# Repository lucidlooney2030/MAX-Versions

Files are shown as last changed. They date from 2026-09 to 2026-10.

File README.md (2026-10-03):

# MAX-Versions

**Current tip (2026-10-02-night):** Gen-AZ dual-rotor copper-centroid femto — see [CHAMPION.md](CHAMPION.md).

**Maximum-electricity**, **modular** generator kits — printable magnetic generators tuned for **max watts always**.

Companion to nightly `generators` exploration archives. This repo keeps the modular max-output line — shared interfaces, current champion, and drop-in kits.

## Status (2026-10-02 ET)

**Champion: Gen-AZ dual-rotor copper-centroid femto AFPM (wound-aware)** — dethrones Gen-AW (~19–40 W vs ~18–38 W @200 RPM; m2m 4.66 held; Ø20 @ R=37.5 over copper centroid; 220 t; former_web 1.20; one-plate 404×404 ≤408).

See **[CHAMPION.md](CHAMPION.md)** and **[WOUND_COIL_RULE.md](WOUND_COIL_RULE.md)**. Prior Gen-A–L were withdrawn for sizing gaps/slots to bare former STLs.

| Kit | Path |
|-----|---|
| Champion | [`champions/2026-10-02-gen-az-dual-rotor-coppercentroid-femto/`](champions/2026-10-02-gen-az-dual-rotor-coppercentroid-femto/) |
| One-plate pack | [`print-packs/gen-az-dual-rotor-coppercentroid-femto/`](print-packs/gen-az-dual-rotor-coppercentroid-femto/) |
| Night runners | [`champions/runners-2026-10-02/`](champions/runners-2026-10-02/) |
| Prior champion | [`champions/2026-10-01-gen-aw-dual-rotor-coppercentroid-pico/`](champions/2026-10-01-gen-aw-dual-rotor-coppercentroid-pico/) |

## Magnet kit (fixed)

| Magnet | Qty | Size |
|---|-----|---|
| Large disks | **16×** | Ø20 × 5 mm (N52 NdFeB) |
| Small disks | **48×** | Ø5 × 5 mm (Halbach / concentrator assist) |

Pockets are typically **Ø20.3 × 5.2** and **Ø5.3 × 5.2** for print clearance.

## Wire

- **26 AWG** — insulated OD ≈ **0.45 mm** (audit assumption)
- **30 AWG** — insulated OD ≈ **0.30 mm** (audit assumption)

Document turns, interconnect (star 3φ preferred), and **wound envelope** used for stack sizing. Gen-AZ: **220 t × 26 AWG** per pancake.

## Printer

- **Anycubic Kobra 3 Max Combo**
- Filament **1.75 mm** (PETG/ABS preferred; PLA OK for prototypes)
- Nozzles: **0.4 mm** default for carriers / formers; **0.6 / 0.8 mm** OK for endbells and coarse shells
- One-plate usable bed: **≤408×408 mm** (not full 420 — Gen-AE first plate at 440 failed)

## Modular interface

Shared mechanical stack (shaft Ø8, 608ZZ, bolt circles, etc.): **[MODULAR_INTERFACE.md](MODULAR_INTERFACE.md)**.

Kits must satisfy **[WOUND_COIL_RULE.md](WOUND_COIL_RULE.md)** before promotion to `champions/`.

## License

See [LICENSE](LICENSE).

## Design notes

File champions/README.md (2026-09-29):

# MAX-Versions champions

**Current tip (2026-09-28-night ET):** [`2026-09-28-gen-an-dual-rotor-coppercentroid-hyper/`](2026-09-28-gen-an-dual-rotor-coppercentroid-hyper/) — Gen-AN dual-rotor copper-centroid hyper (~15–32 W @200 RPM).

Prior tip: [`2026-09-27-gen-ak-dual-rotor-coppercentroid-ultra/`](2026-09-27-gen-ak-dual-rotor-coppercentroid-ultra/) — Gen-AK (~14–30 W).

Same-night runners: [`runners-2026-09-28/`](runners-2026-09-28/).

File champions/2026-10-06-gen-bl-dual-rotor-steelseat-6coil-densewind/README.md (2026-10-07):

# Gen-BL — nightly 2026-10-06 `gen-bl-dual-rotor-steelseat-6coil-densewind`

Generated 2026-10-06 (ET). All numbers from `physics_scorer` (magpylib, N52 Br 1.43 T, PLA = air, 26 AWG @20 °C,
steel back-iron by the scorer's `--back-iron` image method). Full report: [SCORE.md](SCORE.md), field plot:
[bz_midplane.png](bz_midplane.png), extra geometry checks: [GEOM_CHECK.md](GEOM_CHECK.md).

## Design idea

Dense-wind, smaller gap: the wire budget (not the window) limits these machines, so the same ~367 m of 26 AWG is laid layer-by-layer at fill 0.65 into a SHORTER 8.1 mm window (vs 9.0 mm on Gen-BI) with a 17.1 mm build on 29–71 mm sector bobbins. That shrinks the magnet-to-magnet gap 11.6 → 10.7 mm, so every turn sees more flux. Rotors, Ø5 tight-assist map and Ø134 × 4.76 mm steel are identical to Gen-BI (modular: swap in new bobbins, stator, gap sleeve and endbells).

## Honest numbers @ 200 RPM (scorer output only)

| Metric | Value |
|---|---|
| Matched-load power (3φ, V²/4R), **with steel** (`--back-iron`) | **5.299 W** (4.58 W with hot copper @60 °C) |
| Air-core what-if (same kit, no `--back-iron`) | 2.570 W (7.49 V rms/ph) |
| Without the Ø5 assists (`--back-iron --halbach none`) | 4.975 W |
| What-if: only a looser fill 0.60 wind (`--back-iron --fill 0.60`): just 522 t fit the same window (the scorer flags the 566 t claim FAIL at that fill — wind only what fits) | 4.884 W |
| Open-circuit voltage | **10.76 V rms/phase** (18.57 V line) |
| Phase resistance (20 °C) | **16.39 Ω** |
| Turns per coil | **566** (= scorer turns-fit at fill 0.65; do not raise) |
| Peak / mean-over-window Bz | 0.532 / 0.102 T |
| Matched / short-circuit current | 0.33 / 0.66 A per phase |
| Verdict | **PASS** (scorer) · geometry check **PASS** |

Topology **dual_rotor**, 8 poles, 6 coils × 1 stator, star 3φ, 2 coils in series per phase.
Copper total **367 m** of 26 AWG (6 coils × 61.2 m incl. 0.15 m leads) — inside the ~370 m budget of one ~390 m spool.
Champion to beat: Gen-BF 4.380 W (same `--back-iron` mode) → this kit **BEATS** it (1.21×).

**Honesty limits:** the `--back-iron` number is the scorer's **optimistic upper bound**: steel is modelled by first-order images of an
infinite, unsaturated plate. The magnets really sit on the steel (through-pockets), which is the image plane the scorer assumes, but
finite disc size, saturation and eddy/hysteresis losses are not modelled. Air-core coils, no AC loss, ideal series connection, 20 °C copper.

## Magnet polarity / clocking

Rotor A pocket 0 (at the D-flat / rim notch): N toward the stator; alternate N/S around. Rotor B is the same print, flipped to face A:
its pocket 0 (at its notch, which lands on the same D-flat) gets S toward the stator, alternating. Result: every magnet faces an opposite
pole directly across the gap (`rotor_b_offset_deg = 0`, `rotor_b_same_axis = true`; scorer clocking factor 1.000).
Key: D-flat bore + rim index notch = pocket 0, and the steel disc's notch lines up with it. Brace holes at [45, 135, 225, 315]° (flip-symmetric);
steel-clamp M3 holes at [0, 90, 180, 270]° (R30) and [45, 135, 225, 315]° (R63), also flip-symmetric,
so a flipped rotor only mounts aligned. Magnets: 16× Ø20×5 N52 (8 per rotor, R50) + 48× Ø5×5 N52 **diametric** assists
(24 per rotor, between poles at R40 / 50 / 60).

## ⚠️ Ø5 assist magnets — DIAMETRIC only

The 48 × Ø5×5 assists count **only if diametrically magnetised** (magnetisation across the diameter); glue them with the
magnetisation **tangential** (along the circumference), direction per the arrows on `preview.png` (scorer signs {'A': -1, 'B': 1}).
Axially magnetised Ø5 discs do **not** form a Halbach assist and are **not counted** by the scorer; if you only have axial Ø5,
leave the pockets empty and expect ≈4.97 W (scorer, same kit, `--halbach none`). Epoxy each one before the second rotor approaches —
a loose diametric magnet will spin in its pocket to align with the big magnets' field.

## Steel back-iron (REQUIRED for the scored watts)

Buy / cut **2× Ø134 × 4.76 mm (3/16") mild-steel discs** (S235/A36/1008–1018 CRS), OD Ø134, centre hole Ø26, hole map =
`print-packs/laser-cut/steel_backiron_disc.dxf` (generated from `steel_backiron_disc.scad`, same holes as the rotor). Any online
laser-cut service (SendCutSend / OSHCut / local shop) cuts it from the DXF; zinc-plate or paint against rust.
Each disc (stack) sits on the hub side of its rotor carrier around the hub; magnets drop through the pockets onto the steel and are epoxied to it.
Clamp steel + carrier with 8× M3×16 + nuts per rotor.

**Re-use note (Gen-BL):** the disc OD (Ø134), centre hole (Ø26), M3 hole map (R30 at 0/90/180/270°, R63 at 45/135/225/315°), M4 brace holes (R18 at 45°…) and rim notch are **identical to Gen-BI's** `steel_backiron_disc.dxf` (2026-10-05), and so are the rotor carriers (same pocket map) — the same steel discs and rotor carriers work for both kits (rotor STLs verified geometrically identical: same bounds and volume); print new bobbins, stator, gap sleeve and endbells.

Thickness check (`_build/steel_flux.py`, magpylib, not part of the scorer): flux entering the steel ≈ 0.278 mWb per pole.
Half of it returns each way through the disc: ≈0.54 T if it spreads over the full radial width, ≈1.46 T if it stays in a
band one magnet wide (worst case) at 4.76 mm. (At 3 mm the worst-case band would be ≈2.3 T, i.e. saturated — that is why tonight's
kits use ≥4.76 mm.) Without the steel the scorer gives only **2.57 W** — the steel is not optional.

## Parts to print (`print-packs/parts/`; all on ONE plate in `print-packs/one-plate/`)

| File | Qty | Notes |
|---|---|---|
| `rotor_face_a.stl` | 1 | flat (magnet) face down, hub up; through pockets |
| `rotor_face_b.stl` | 1 | identical pocket map (offset 0), flipped at assembly |
| `stator_core.stl` | 1 | 6 through bays, bobbins flush both faces, frame holes between stations |
| `coil_former.stl` | **6** | bobbin base, flange down |
| `coil_lid.stl` | **6** | flange down; CA-glue onto hub before winding |
| `endbell_front.stl` / `endbell_rear.stl` | 1 / 1 | 608 boss; boss side needs supports |
| `frame_standoff.stl` | 12 | 29.6 mm tubes on the M3 frame rods (stator ↔ endbells, outside the rotor) |
| `gap_sleeve.stl` | 1 | 10.7 mm shaft spacer between the two rotors (sets the gap, takes the magnet pull) |
| `gap_spacer.stl` | 6 | 0.50 mm assembly feeler shims |
| `shaft_collar.stl` | 4 | D-flat bore, M3 set screw on the flat |
| `fit_coupon.stl` | 1 | print FIRST: Ø20/Ø5 through pockets, 608 seat, D-bore, gap shim, bay slice |

One-plate: `print-packs/one-plate/one_plate_layout.stl`, bbox measured from the STL **407.9 × 408.0 mm**
(≤ 410; Kobra 3 Max 420 bed), preview `print-packs/one-plate/preview.png`. PLA/PETG, 0.4 mm nozzle, 0.20 mm layers
(0.6 mm nozzle is fine for endbells/standoffs). Binary STL, mm. Print the fit coupon on its own first (it is also on the plate).

## Hardware BOM (non-printed)

- Steel: 2× Ø134 × 4.76 mm (3/16") mild-steel discs · 2× 608 bearings · Ø8 mm D-flat shaft ≥ 134 mm (stack 99 mm + collars)
- 6× M3 threaded rod ≈ 97 mm + nuts/washers (frame) · 16× M3×16 + nuts (steel clamp)
- 2× M3 heat-set inserts (radial, in each rotor hub, below the steel) + 2× M3×6 set screws onto the D-flat; 4× M3 set screws for collars
- 4× M4 threaded rod ~150 mm + 16 nuts (TEMPORARY jack/brace rods for assembly) · 1.75 mm filament (bobbin pins) · epoxy + CA
- 367 m 26 AWG enamelled copper (0.45 mm OD)

## Winding

Bobbin window 8.10 × 17.10 mm → 18 layers, **566 turns** of 26 AWG at fill 0.65
(61.2 m per coil — use a drill/lathe winding jig and a turn counter). Copper sector r 29–71 mm × 52.68°.
Wind **before** assembly; copper only between the 0.8 mm flanges, nothing proud. Magnet→wound envelope 0.60 mm
(as-built pocket recess 0.10 mm; ≥0.5 PASS); neighbouring bobbins: clearance between neighbouring former footprints at r=29: 1.70 mm; stator web between bays ≥1.2 mm (GEOM_CHECK.md).

Wiring (3φ star, from the scorer phasors): `S0:A+ S1:C+ S2:B+ S3:A+ S4:C+ S5:B+` — same-letter coils in series per phase, '−' = swap that coil's leads.
Join the three phase ends to a common star point; take A/B/C to a 3-phase bridge rectifier (6× Schottky, e.g. SB560) for DC.
Series vs parallel: wiring the coils of each phase in parallel instead of series halves Voc and quarters R (about 5.38 V rms/ph, 4.10 Ω)
but gives the **same matched-load watts** — it only moves the load-matching point. Series is recommended (rectifier drop is a smaller fraction).

**Dense winding is required for the scored turns.** The scored turns assume a dense, layer-by-layer wind at fill 0.65 (insulated-wire area / window; the scorer cap). Use a winding jig on a drill/lathe with a turn counter, lay each layer side-by-side with light back-tension, and do not scramble-wind: a scramble wind only reaches ≈0.55–0.60 and then the window holds fewer turns (scorer what-if `--fill 0.60` is in the table above). Never wind more than the listed turns — the copper must stay below the flanges.

## Assembly order / safety

1. Print the fit coupon; check Ø20/Ø5 fit in the through-pockets, the 608 seat and the D-bore on your shaft; test-drop a wound bobbin in the bay slice.
2. Glue each lid onto its base hub, wind 566 t in 18 even layers, leads out through the lid slots.
3. Drop bobbins into the stator bays (lid/tab side = +Z, lead-groove face), pin with 1.75 mm filament, epoxy. Wire per the map above.
4. Rotor A: bolt the steel to the carrier, then seat magnets one at a time through the pockets onto the steel (polarity rule above), epoxy.
   **Keep the two magnet rotors far apart (> 30 cm) and away from steel tools** until step 6.
5. Shaft + rotor A + gap sleeve; slide the stator over the sleeve, frame rods + standoffs to the front endbell.
6. **Clap hazard — brace before seating the second magnet face:** steel-backed N52 across a 10.7 mm gap pulls very hard. Thread the 4 temporary
   M4 rods through rotor B / stator / rotor A (brace holes R18) with nuts on both sides, and lower rotor B onto the gap sleeve by turning the nuts. Never let it jump.
7. Check the gap with the 0.50 mm shims, set hub set screws + collars, fit the rear endbell.
8. **Remove the temporary M4 rods and every shim before spinning.** Spin by hand first and listen for rubbing.
9. **Brim** the 0.8 mm bobbin flanges and the thin 1.2 mm stator webs when printing.

Re-score: `/workspace/generators/tools/physics_scorer/score_kit score /workspace/generators/2026-10-06/gen-bl-dual-rotor-steelseat-6coil-densewind --out /workspace/generators/2026-10-06/gen-bl-dual-rotor-steelseat-6coil-densewind --back-iron` (air-core: drop `--back-iron`, use another `--out`).

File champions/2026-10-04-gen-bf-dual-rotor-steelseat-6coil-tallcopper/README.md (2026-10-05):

# Gen-BF — nightly 2026-10-04 `gen-bf-dual-rotor-steelseat-6coil-tallcopper`

Generated 2026-10-04 (ET). All numbers from `physics_scorer` (magpylib, N52 Br 1.43 T, PLA = air, 26 AWG @20 °C,
steel back-iron by the scorer's `--back-iron` image method). Full report: [SCORE.md](SCORE.md), field plot:
[bz_midplane.png](bz_midplane.png), extra geometry checks: [GEOM_CHECK.md](GEOM_CHECK.md).

## Design idea

8-pole / 6-coil dual rotor with big 51.5 deg sector coils and TALL 9.9 mm copper, magnets seated directly on 3 mm steel back-iron discs (through-pockets) so the field stays high across a wide gap.

## Honest numbers @ 200 RPM (scorer output only)

| Metric | Value |
|---|---|
| Matched-load power (3φ, V²/4R) | **4.380 W** (3.79 W with hot copper @60 °C) |
| Open-circuit voltage | **9.04 V rms/phase** (15.64 V line) |
| Phase resistance (20 °C) | **14.00 Ω** |
| Turns per coil | **571** (= scorer turns-fit at fill 0.60; do not raise) |
| Peak / mean-over-window Bz | 0.474 / 0.123 T |
| Matched / short-circuit current | 0.32 / 0.65 A per phase |
| Verdict | **PASS** (scorer) · geometry check **PASS** |

Topology **dual_rotor**, 8 poles, 6 coils × 1 stator, star 3φ, 2 coils in series per phase.
Copper total **314 m** of 26 AWG (6 coils × 52.3 m incl. 0.15 m leads) — fits the ~390 m spool.
Champion to beat was Gen-BE 1.684 W → this kit **BEATS** it (2.60×).

**Honesty limits:** the steel is modelled by first-order images (infinite, unsaturated plate) → upper bound. Here the magnets
really do sit on the steel (through-pockets), which is exactly the image-plane the scorer assumes (last night's kits had ~2.3 mm
of PLA between magnet and steel). Air-core, no eddy/AC loss, ideal series connection, 20 °C copper.

## Magnet polarity / clocking

Rotor A pocket 0 (at the D-flat / rim notch): N toward the stator; alternate N/S around. Rotor B is the same print, flipped to face A: its pocket 0 (at its notch, which lands on the same D-flat) gets S toward the stator, alternating. Result: every magnet faces an opposite pole directly across the gap (rotor_b_offset_deg = 0, rotor_b_same_axis = true).
Key: D-flat bore + rim index notch = pocket 0, and the steel disc's notch lines up with it. Brace holes at [45, 135, 225, 315]° (flip-symmetric);
steel-clamp M3 holes at [0, 90, 180, 270]° (R27) and [0, 90, 180, 270]° (R57), also flip-symmetric.
Magnets: 16x O20x5 N52 (8 per rotor) + 48x O5x5 N52 **diametric** assists (24 per rotor, 3 radii between poles).

## ⚠️ O5 assist magnets — DIAMETRIC only

The 48 × Ø5×5 assists **must be diametrically magnetised** (magnetisation across the diameter) and glued with the
magnetisation **tangential** (along the circumference), direction per the arrows on `preview.png` (scorer signs {'A': -1, 'B': 1}).
Axially magnetised Ø5 discs do **not** form a Halbach assist and are **not counted** by the scorer; if you only have axial Ø5,
leave the pockets empty and expect ≈4.14 W (scorer, same kit, `--halbach none`). Glue each one (CA/epoxy) before the
second rotor approaches — a loose diametric magnet will spin in its pocket to align with the big magnets' field.

## Steel back-iron (REQUIRED for the scored watts)

Buy **2× mild-steel discs Ø127 × 3 mm** (S235/A36/1008–1018 CRS), centre hole Ø26, hole map =
`print-packs/laser-cut/steel_backiron_disc.dxf` (generated from `steel_backiron_disc.scad`, same holes as the rotor). Any online
laser-cut service (SendCutSend / OSHCut / local shop) cuts this directly from the DXF; zinc-plate or paint against rust.
Each disc sits on the hub side of its rotor carrier; magnets drop through the pockets onto the steel and are epoxied to it.
Clamp disc + carrier with 8× M3×12 + nuts per rotor.
Thickness: with ~0.21 mWb per pole (magpylib, at the magnet face) the average steel flux density is ≈0.70 T at 3 mm (locally higher right
behind the magnets) — 3 mm is the minimum; 4 mm also fits the hub (10 mm) and adds margin. Do **not** use 1.5 mm (≈1.3–1.5 T average, i.e. near saturation, so the image-method watts would not hold).
Without the steel discs (air-core what-if, same kit, no `--back-iron`) the scorer gives only **2.15 W** — the steel is not optional.

## Parts to print (`print-packs/parts/`; all on ONE plate in `print-packs/one-plate/`)

| File | Qty | Notes |
|---|---|---|
| `rotor_face_a.stl` | 1 | flat (magnet) face down, hub up; through pockets |
| `rotor_face_b.stl` | 1 | identical pocket map (offset 0), flipped at assembly |
| `stator_core.stl` | 1 | 6 through bays, bobbins flush both faces, frame holes between stations |
| `coil_former.stl` | **6** | bobbin base, flange down |
| `coil_lid.stl` | **6** | flange down; CA-glue onto hub before winding |
| `endbell_front.stl` / `endbell_rear.stl` | 1 / 1 | 608 boss; boss side needs supports |
| `frame_standoff.stl` | 12 | 27.6 mm tubes on the M3 frame rods (stator ↔ endbells, outside the rotor) |
| `gap_sleeve.stl` | 1 | 12.5 mm shaft spacer between the two rotors (sets the gap, takes the magnet pull) |
| `gap_spacer.stl` | 6 | 0.50 mm assembly feeler shims |
| `shaft_collar.stl` | 4 | D-flat bore, M3 set screw on the flat |
| `fit_coupon.stl` | 1 | print FIRST: O20/O5 through pockets, 608 seat, D-bore, bay slice |

One-plate: `print-packs/one-plate/one_plate_layout.stl`, bbox measured from the STL **408.5 × 409.0 mm**
(≤ 410; Kobra 3 Max 420 bed), preview `print-packs/one-plate/preview.png`. PLA/PETG, 0.4 mm nozzle, 0.20 mm layers
(0.6 mm nozzle is fine for endbells/standoffs). Binary STL, mm.

## Hardware BOM (non-printed)

- 2× steel discs (above) · 2× 608 bearings · Ø8 mm D-flat shaft ≥ 132 mm (stack 97 mm + collars)
- 6× M3 threaded rod ≈ 95 mm + nuts/washers (frame) · 16× M3×12 + nuts (steel clamp)
- 2× M3 heat-set inserts (radial, in each rotor hub) + 2× M3×6 set screws onto the D-flat; 4× M3 set screws for collars
- 4× M4 threaded rod ~150 mm + 16 nuts (TEMPORARY jack/brace rods for assembly) · 1.75 mm filament (bobbin pins) · epoxy + CA

## Winding

Bobbin window 9.90 × 15.30 mm → 22 layers, **571 turns** of 26 AWG at fill 0.60
(52.3 m per coil — use a drill/lathe winding jig and a turn counter). Copper sector r 25–62 mm × 51.51°.
Wind **before** assembly; nothing proud of the 0.8 mm flanges. Magnet→wound envelope 0.60 mm (as-built pocket recess 0.10 mm; ≥0.5 PASS).

Wiring (3φ star, from the scorer phasors): `S0:A+ S1:C+ S2:B+ S3:A+ S4:C+ S5:B+` — same-letter coils in series per phase, '−' = swap that coil's leads.

## Assembly order / safety

1. Print the fit coupon; check Ø20/Ø5 fit in the through-pockets, the 608 seat and the D-bore on your shaft; test-drop a wound bobbin in the bay slice.
2. Glue each lid onto its base hub, wind 571 t in 22 even layers, leads out through the lid slots.
3. Drop bobbins into the stator bays (lid/tab side = +Z, lead-groove face), pin with 1.75 mm filament, epoxy. Wire per the map above.
4. Rotor A: bolt the steel disc to the carrier, then seat magnets one at a time through the pockets onto the steel (polarity rule above), epoxy.
   **Keep the two magnet rotors far apart (> 30 cm) and away from steel tools** until step 6.
5. Shaft + rotor A + gap sleeve; slide the stator over the sleeve, frame rods + standoffs to the front endbell.
6. **Clap hazard — brace before seating the second magnet face:** thread the 4 temporary M4 rods through rotor B / stator / rotor A
   (brace holes R18) with nuts on both sides, and lower rotor B onto the gap sleeve by turning the nuts. Never let it jump.
7. Check the gap with the 0.50 mm shims, set hub set screws + collars, fit the rear endbell.
8. **Remove the temporary M4 rods and every shim before spinning.** Spin by hand first and listen for rubbing.
9. **Brim** the 0.8 mm bobbin flanges and the thin stator webs (1.2 mm between bays) when printing.

## Kit magnet / wire budget

16× Ø20×5 N52 + 48× Ø5×5 N52 (diametric) + 314 m of 26 AWG (of ~390 m) + 2 steel discs.

Re-score: `/workspace/generators/tools/physics_scorer/score_kit score /workspace/generators/2026-10-04/gen-bf-dual-rotor-steelseat-6coil-tallcopper --out /workspace/generators/2026-10-04/gen-bf-dual-rotor-steelseat-6coil-tallcopper --back-iron`

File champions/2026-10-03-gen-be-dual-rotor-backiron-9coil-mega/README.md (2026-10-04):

# Gen-BE — nightly 2026-10-03 `gen-be-dual-rotor-backiron-9coil-mega`

Generated 2026-10-03. All numbers from `physics_scorer` (magpylib, N52 Br 1.43 T, PLA = air, 26 AWG @20 °C, steel back-iron images).
Full report: [SCORE.md](SCORE.md), field plot: [bz_midplane.png](bz_midplane.png).

## Design idea

Nine-coil dual-rotor with tall bobbins (former_web 3.60 mm) and two buyable mild-steel back-iron discs; image-method steel boost.

## Honest numbers @ 200 RPM

| Metric | Value |
|---|---|
| Matched-load power (3φ, V²/4R) | **1.684 W** |
| Open-circuit voltage | **2.41 V rms/phase** (4.17 V line) |
| Phase resistance (20 °C) | **2.58 Ω** |
| Turns per coil | **107** (fits; do not raise) |
| Peak / mean-over-window Bz | 0.750 / 0.436 T |
| Short-circuit current | 0.93 A/phase (resistance-limited) |
| Verdict | **PASS** |

Matched load = 2.6 Ω/phase (star); I_matched 0.47 A. Copper total 58 m (9 coils × 6.43 m).
Topology **dual_rotor**, 8 poles, 9 coils × 1 stator(s). Steel: YES (scored with --back-iron).

Baseline Gen-BA (corrected): 0.615 W. This kit BEATS that baseline.

## Magnet polarity / clocking

`rotor_b_offset_deg = 0`. Rotor A pocket 0 (at the D-flat / rim notch): N toward the stator; alternate N/S around. Rotor B is printed identically and flipped to face A: its pocket 0 (at its notch, which lands on the same D-flat) gets S toward the stator, alternating. Result: every magnet faces an opposite pole directly across the gap.
D-flat bore + rim index notch = pocket 0. Brace holes at 45/135/225/315° (flip-symmetric).

## ⚠️ Halbach assist magnets

The 48 × Ø5×5 assist magnets **must be diametrically magnetised** and installed with magnetisation tangential (along the circumference).
Axially magnetised Ø5 do **not** form a Halbach array and are not counted by the scorer. Signs from scorer: {'A': -1, 'B': 1}.

## Steel back-iron (required for scored watts)

Buy and fit **2x mild-steel discs Ø156 x 1.5 mm (buyable laser-cut / washer stock), centre hole Ø32 for hub, behind each rotor magnet face**.

Seat each disc on the **back** of the rotor (opposite the magnet face), concentric with the hub. Epoxy or screw through non-pocket areas.
Scored with `score_kit ... --back-iron` (first-order image method — optimistic upper bound assuming unsaturated infinite plates).
Without the steel discs, air-core output drops by roughly half (re-score without `--back-iron` before claiming watts).

## Parts to print (`print-packs/parts/`; one plate in `print-packs/one-plate/`)

| File | Qty | Notes |
|---|---|---|
| `rotor_face_a.stl` | 1 | print magnet face DOWN |
| `rotor_face_b.stl` | 1 | identical pocket map (offset 0) |
| `stator_core.stl` | 1 | through bays, bobbins flush both faces |
| `coil_former.stl` | **9** | bobbin base, flange down |
| `coil_lid.stl` | **9** | flange down; CA-glue onto hub before winding |
| `gap_spacer.stl` | 9 | 0.50 mm assembly shims |
| `endbell_front.stl` / `endbell_rear.stl` | 1 / 1 | both on the plate; boss side needs supports |
| `shaft_collar.stl` | 4 | D-flat bore, M3 set screw on the flat |
| `fit_coupon.stl` | 1 | print first |

One-plate: `print-packs/one-plate/one_plate_layout.stl`, measured **409.0 × 409.0 mm** (≤ 410, Kobra 3 Max 420 bed).

## Winding

Bobbin window 3.60 × 7.9 mm → 8 layers, **107 turns** of 26 AWG at fill 0.60.
Copper sector r 26–50 mm × 31.84°. Wind **before** assembly. Magnet→wound envelope 0.70 mm (≥0.5 PASS).

## Assembly order / safety

1. Print coupon; check magnet fit and D-bore on your shaft.
2. Glue each lid onto its base hub, wind 107 turns of 26 AWG in 8 even layers, leads out through lid grooves.
3. Drop bobbins into stator bays, pin with 1.75 mm filament, epoxy. Wire 3φ star per scorer map: `S0:A+ S1:A- S2:B- S3:B+ S4:B- S5:C- S6:C+ S7:C- S8:A-`.
4. Magnets per polarity rule (D-flat / notch = pocket 0). Fit steel back-iron discs on rotor backs before seating magnets if easier for your process.
5. **Brace M4 before seating the second magnet face** (clap hazard — dual faces / mid rotor attracts hard). Set gaps with 0.50 mm shims, lock collars.
6. **Brim on 0.60 mm flanges / thin webs.** Remove temporary braces and shims **before spinning**.

## Kit magnet / wire budget

16× Ø20×5 N52 + 48× Ø5×5 N52 (diametric assists) + ~58 m of 26 AWG (of ~390 m spool).

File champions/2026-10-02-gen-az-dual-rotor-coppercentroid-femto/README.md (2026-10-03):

# Gen-AZ — Dual-rotor copper-centroid femto AFPM / wound-aware 12-coil 3φ

**PRIMARY challenger vs Gen-AW** (night 2026-10-02 ET). Dual topology with `m2m=4.66 mm` + copper-centroid Ø20 @ **R=37.5** + **220 t** + `former_web=1.20` while magnet↔wound stays **0.50 mm PASS**.

**Wound gate: PASS** — see [WOUND_ENVELOPE.md](WOUND_ENVELOPE.md).

## Wound envelope (mandatory)

| Param | Value | Notes |
|---|---|---|
| Wire | **26 AWG** | insulated OD **0.45 mm**; ~1 lb spool ≈ 390 m |
| Turns | **220** / pancake | 12×220×~0.124 m ≈ **328 m** copper (fits 1 lb) |
| fill | **0.70** | packing factor |
| layers_per_face | **2** | axial layers proud of each flange |
| `wind_build_axial` | **0.63 mm** | `2 × 0.45 × 0.7` |
| `wind_build_radial` | **0.945 mm** | `3 × 0.45 × 0.7` |
| `former_web` / `flange_t` | **1.20 / 0.6 mm** | print floor LB walls |
| `former_bare_h` | **2.40 mm** | |
| `coil_envelope_h` | **3.66 mm** | bare + 2×wind_build_axial |
| `run_clear` | **0.50 mm** | magnet → **wound** (each gap) |
| `gap_spacer_h` | **1.13 mm** | `run_clear + wind_build_axial` |
| `m2m` | **4.66 mm** | `coil_envelope_h + 2×run_clear` (**NOT** bare) |
| magnet→wound | **0.50 mm** | **PASS** both sides (≥0.5) |

Stator bays expand for wound radial outline. Explicit params in `parameters.scad`. Coil window: coil_id_r=13.5, coil_od_r=61.5, span_deg=26.0 (centroid ~(13.5+61.5)/2=37.5).

## Why this design

Gen-AW: Ø20 @ R=38.0, 215 t, former_web 1.20, m2m 4.66, ~18–38 W. Gen-AZ tightens copper-centroid to **R=37.5**, adds **+5 turns** (220), keeps former_web **1.20** → envelope 3.66 / m2m **4.66**, Halbach Ø5 @ {22.5,37.5,54.5}. Midpoint ~29.5 W vs AW ~28 W.

## Magnet inventory (full kit)

| Kit | Qty | Placement |
|-----|-----|---|
| Ø20×5 | **8** | Rotor A @ R=37.5 mm, 45° steps |
| Ø20×5 | **8** | Rotor B @ R=37.5 mm, offset **+22.5°** |
| Ø5×5 | **24** | Rotor A Halbach @ R={22.5,37.5,54.5} |
| Ø5×5 | **24** | Rotor B Halbach (+22.5°) |

Pockets: **Ø20.3×5.2**, **Ø5.3×5.2**.

### Polarity map

**Rotor A (+Z):** alternate N-S (even indices N toward stator).  
**Rotor B (−Z):** alternate N-S with N toward stator on even indices (flux through coils).  
**Halbach smalls:** mid circumferential; inner/outer reinforce pole tips AND extend radial coverage onto inner/outer copper.

### ⚠️ DUAL-ROTOR CLAP WARNING
Brace with **M4 rods @ R≈68** **BEFORE** seating the second magnet face. Glue one rotor completely, dry-fit wound stator + gap_spacers, brace, then approach second rotor slowly. **Wind all 12 formers before assembly.** Ultra-micro-gap (0.50 mm) leaves **minimal** forgiveness — do not skip braces. Flanges 0.60 mm / web 1.20 mm: **print with brim**, verify no warp before winding.

## Coils

- **12** pancakes — 26 AWG × 220 t; star 3φ
- Mean turn ~0.124 m → copper budget ~328 m on 1 lb 26 AWG

## Stack

```
rotor A magnet face
  └── run_clear 0.50 mm
wound copper (+Z face)
  └── coil_envelope_h 3.66 through mid stator
wound copper (−Z face)
  └── run_clear 0.50 mm
rotor B magnet face
—— m2m = 4.66 mm ——
```

## Estimated EMF / power

Method (consistent with Gen-AW night): rough AFPM scaling from copper window area × turns × B_gap × RPM. Assumptions: N52 Halbach-boosted B_gap ≈ **0.75–1.14 T** per gap (tighter R than AW), fill 0.70, series/3φ star, dual-face coupling where topology allows.

| RPM | Est. combined RMS | Est. matched power |
|-----|---|---|
| 120 | — | ~13–19 W |
| **200** | **~23–50 V** | **~19–40 W** |
| 300 | — | ~36–60 W |
| 500–1000 | — | ~55–135 W (thermal) |

## Modular interface

| Spec | Value |
|---|---|
| Shaft | Ø8 / bore Ø8.35 |
| Bearings | 608ZZ seats Ø21.85×7.2 |
| Hub | Ø30×10 |
| Endbell / stator bolts | **6× M3 @ R=72** (Gen-E family) |
| Brace | **4× M4 @ R≈68** (REQUIRED) |
| M3 clear | Ø3.4–3.5 |
| Heat-set | M3 inserts preferred |

## Parts to print

| File | Qty | Notes |
|---|-----|---|
| `rotor_face_a.stl` | 1 | Magnet face up; brim |
| `rotor_face_b.stl` | 1 | +22.5° pocket map |
| `stator_core.stl` | 1 | Wound-sized bays |
| `coil_former.stl` | **12** | **Wind before assembly**; thin flanges + brim |
| `gap_spacer.stl` | **12** | h=`gap_spacer_h` 1.13 |
| `endbell_front.stl` | 1 | |
| `endbell_rear.stl` | 1 | (or print front ×2) |
| `shaft_collar.stl` | 4 | |
| `fit_coupon.stl` | 1 | Print first |

One-plate: see `print-packs/one-plate/` (Kobra 3 Max ≤408×408 mm). Measured bbox **404×404 mm**.

## BOM (non-print)

| Item | Qty |
|---|-----|
| NdFeB Ø20×5 N52 | 16 |
| NdFeB Ø5×5 N52 | 48 |
| 26 AWG magnet wire | ≤328 m of ~390 m spool |
| 608ZZ bearings | 2 |
| M3 heat-set inserts + bolts | as needed |
| M4 brace rods | 4 |
| Ø8 shaft | 1 |

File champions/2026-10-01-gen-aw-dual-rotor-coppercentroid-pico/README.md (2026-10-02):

# Gen-AW — Dual-rotor copper-centroid pico AFPM / wound-aware 12-coil 3φ

**PRIMARY challenger vs Gen-AT** (night 2026-10-01 ET). Dual topology with `m2m=4.66 mm` + copper-centroid Ø20 @ **R=38.0** + **215 t** + `former_web=1.20` while magnet↔wound stays **0.50 mm PASS**.

**Wound gate: PASS** — see [WOUND_ENVELOPE.md](WOUND_ENVELOPE.md).

## Wound envelope (mandatory)

| Param | Value | Notes |
|---|---|---|
| Wire | **26 AWG** | insulated OD **0.45 mm**; ~1 lb spool ≈ 390 m |
| Turns | **215** / pancake | 12×215×~0.126 m ≈ **325 m** copper (fits 1 lb) |
| fill | **0.70** | packing factor |
| layers_per_face | **2** | axial layers proud of each flange |
| `wind_build_axial` | **0.63 mm** | `2 × 0.45 × 0.7` |
| `wind_build_radial` | **0.945 mm** | `3 × 0.45 × 0.7` |
| `former_web` / `flange_t` | **1.20 / 0.6 mm** | print floor LB walls |
| `former_bare_h` | **2.40 mm** | |
| `coil_envelope_h` | **3.66 mm** | bare + 2×wind_build_axial |
| `run_clear` | **0.50 mm** | magnet → **wound** (each gap) |
| `gap_spacer_h` | **1.13 mm** | `run_clear + wind_build_axial` |
| `m2m` | **4.66 mm** | `coil_envelope_h + 2×run_clear` (**NOT** bare) |
| magnet→wound | **0.50 mm** | **PASS** both sides (≥0.5) |

Stator bays expand for wound radial outline. Explicit params in `parameters.scad`. Coil window: coil_id_r=14.0, coil_od_r=62.0, span_deg=26.0.

## Why this design

Gen-AT: Ø20 @ R=38.5, 210 t, former_web 1.22, m2m 4.68, ~17–36 W. Gen-AW tightens copper-centroid to **R=38.0**, adds **+5 turns** (215), thins former_web to **1.20** → envelope 3.66 / m2m **4.66**, Halbach Ø5 @ {23.0,38.0,55.0}. Midpoint ~28 W vs AT ~26.5 W.

## Magnet inventory (full kit)

| Kit | Qty | Placement |
|-----|-----|---|
| Ø20×5 | **8** | Rotor A @ R=38.0 mm, 45° steps |
| Ø20×5 | **8** | Rotor B @ R=38.0 mm, offset **+22.5°** |
| Ø5×5 | **24** | Rotor A Halbach @ R={23.0,38.0,55.0} |
| Ø5×5 | **24** | Rotor B Halbach (+22.5°) |

Pockets: **Ø20.3×5.2**, **Ø5.3×5.2**.

### Polarity map

**Rotor A (+Z):** alternate N-S (even indices N toward stator).  
**Rotor B (−Z):** alternate N-S with N toward stator on even indices (flux through coils).  
**Halbach smalls:** mid circumferential; inner/outer reinforce pole tips AND extend radial coverage onto inner/outer copper.

### ⚠️ DUAL-ROTOR CLAP WARNING
Brace with **M4 rods @ R≈68** **BEFORE** seating the second magnet face. Glue one rotor completely, dry-fit wound stator + gap_spacers, brace, then approach second rotor slowly. **Wind all 12 formers before assembly.** Ultra-micro-gap (0.50 mm) leaves **minimal** forgiveness — do not skip braces. Flanges 0.60 mm / web 1.20 mm: **print with brim**, verify no warp before winding.

## Coils

- **12** pancakes — 26 AWG × 215 t; star 3φ
- Mean turn ~0.126 m → copper budget ~325 m on 1 lb 26 AWG

## Stack

```
rotor A magnet face
  └── run_clear 0.50 mm
wound copper (+Z face)
  └── coil_envelope_h 3.66 through mid stator
wound copper (−Z face)
  └── run_clear 0.50 mm
rotor B magnet face
—— m2m = 4.66 mm ——
```

## Estimated EMF / power

Method (consistent with Gen-AT night): rough AFPM scaling from copper window area × turns × B_gap × RPM. Assumptions: N52 Halbach-boosted B_gap ≈ **0.74–1.12 T** per gap (tighter m2m/R than AT), fill 0.70, series/3φ star, dual-face coupling where topology allows.

| RPM | Est. combined RMS | Est. matched power |
|-----|---|---|
| 120 | — | ~12–18 W |
| **200** | **~22–48 V** | **~18–38 W** |
| 300 | — | ~34–58 W |
| 500–1000 | — | ~52–130 W (thermal) |

## Modular interface

| Spec | Value |
|---|---|
| Shaft | Ø8 / bore Ø8.35 |
| Bearings | 608ZZ seats Ø21.85×7.2 |
| Hub | Ø30×10 |
| Endbell / stator bolts | **6× M3 @ R=72** (Gen-E family) |
| Brace | **4× M4 @ R≈68** (REQUIRED) |
| M3 clear | Ø3.4–3.5 |
| Heat-set | M3 inserts preferred |

## Parts to print

| File | Qty | Notes |
|---|-----|---|
| `rotor_face_a.stl` | 1 | Magnet face up; brim |
| `rotor_face_b.stl` | 1 | +22.5° pocket map |
| `stator_core.stl` | 1 | Wound-sized bays |
| `coil_former.stl` | **12** | **Wind before assembly**; thin flanges + brim |
| `gap_spacer.stl` | **12** | h=`gap_spacer_h` 1.13 |
| `endbell_front.stl` | 1 | |
| `endbell_rear.stl` | 1 | (or print front ×2) |
| `shaft_collar.stl` | 4 | |
| `fit_coupon.stl` | 1 | Print first |

One-plate: see `print-packs/one-plate/` (Kobra 3 Max ≤408×408 mm). Measured bbox **404×404 mm**.

## BOM (non-print)

| Item | Qty |
|---|-----|
| NdFeB Ø20×5 N52 | 16 |
| NdFeB Ø5×5 N52 | 48 |
| 26 AWG magnet wire | ≤325 m of ~390 m spool |
| 608ZZ bearings | 2 |
| M3 heat-set inserts + bolts | as needed |
| M4 brace rods | 4 |
| Ø8 shaft | 1 |

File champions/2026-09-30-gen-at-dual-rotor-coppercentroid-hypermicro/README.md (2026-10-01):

# Gen-AT — Dual-rotor copper-centroid hypermicro AFPM / wound-aware 12-coil 3φ

**PRIMARY challenger vs Gen-AQ** (night 2026-09-30 ET). Dual topology with `m2m=4.68 mm` + copper-centroid Ø20 @ **R=38.5** + **210 t** + `former_web=1.22` while magnet↔wound stays **0.50 mm PASS**.

**Wound gate: PASS** — see [WOUND_ENVELOPE.md](WOUND_ENVELOPE.md).

## Wound envelope (mandatory)

| Param | Value | Notes |
|---|---|---|
| Wire | **26 AWG** | insulated OD **0.45 mm**; ~1 lb spool ≈ 390 m |
| Turns | **210** / pancake | 12×210×~0.128 m ≈ **323 m** copper (fits 1 lb) |
| fill | **0.70** | packing factor |
| layers_per_face | **2** | axial layers proud of each flange |
| `wind_build_axial` | **0.63 mm** | `2 × 0.45 × 0.7` |
| `wind_build_radial` | **0.945 mm** | `3 × 0.45 × 0.7` |
| `former_web` / `flange_t` | **1.22 / 0.6 mm** | thinner web vs prior (LB ≥1.2) |
| `former_bare_h` | **2.42 mm** | |
| `coil_envelope_h` | **3.68 mm** | bare + 2×wind_build_axial |
| `run_clear` | **0.50 mm** | magnet → **wound** (each gap) |
| `gap_spacer_h` | **1.13 mm** | `run_clear + wind_build_axial` |
| `m2m` | **4.68 mm** | `coil_envelope_h + 2×run_clear` (**NOT** bare) |
| magnet→wound | **0.50 mm** | **PASS** both sides (≥0.5) |

Stator bays expand for wound radial outline. Explicit params in `parameters.scad`. Coil window: coil_id_r=14.5, coil_od_r=62.5, span_deg=26.0.

## Why this design

Gen-AQ: Ø20 @ R=39.0, 205 t, former_web 1.25, m2m 4.71, ~16–34 W. Gen-AT tightens copper-centroid to **R=38.5**, adds **+5 turns** (210), thins former_web to **1.22** → envelope 3.68 / m2m **4.68**, Halbach Ø5 @ {23.5,38.5,55.5}. Midpoint ~26.5 W vs AQ ~25 W.

## Magnet inventory (full kit)

| Kit | Qty | Placement |
|-----|-----|---|
| Ø20×5 | **8** | Rotor A @ R=38.5 mm, 45° steps |
| Ø20×5 | **8** | Rotor B @ R=38.5 mm, offset **+22.5°** |
| Ø5×5 | **24** | Rotor A Halbach @ R={23.5,38.5,55.5} |
| Ø5×5 | **24** | Rotor B Halbach (+22.5°) |

Pockets: **Ø20.3×5.2**, **Ø5.3×5.2**.

### Polarity map

**Rotor A (+Z):** alternate N-S (even indices N toward stator).  
**Rotor B (−Z):** alternate N-S with N toward stator on even indices (flux through coils).  
**Halbach smalls:** mid circumferential; inner/outer reinforce pole tips AND extend radial coverage onto inner/outer copper.

### ⚠️ DUAL-ROTOR CLAP WARNING
Brace with **M4 rods @ R≈68** **BEFORE** seating the second magnet face. Glue one rotor completely, dry-fit wound stator + gap_spacers, brace, then approach second rotor slowly. **Wind all 12 formers before assembly.** Ultra-micro-gap (0.50 mm) leaves **minimal** forgiveness — do not skip braces. Flanges 0.60 mm / web 1.22 mm: **print with brim**, verify no warp before winding.

## Coils

- **12** pancakes — 26 AWG × 210 t; star 3φ
- Mean turn ~0.128 m → copper budget ~323 m on 1 lb 26 AWG

## Stack

```
rotor A magnet face
  └── run_clear 0.50 mm
wound copper (+Z face)
  └── coil_envelope_h 3.68 through mid stator
wound copper (−Z face)
  └── run_clear 0.50 mm
rotor B magnet face
—— m2m = 4.68 mm ——
```

## Estimated EMF / power

Method (consistent with Gen-AQ night): rough AFPM scaling from copper window area × turns × B_gap × RPM. Assumptions: N52 Halbach-boosted B_gap ≈ **0.74–1.10 T** per gap (thinner m2m + tighter overlap), fill 0.70, series/3φ star, dual-face coupling where topology allows.

| RPM | Est. combined RMS | Est. matched power |
|-----|---|---|
| 120 | — | ~11–17 W |
| **200** | **~21–46 V** | **~17–36 W** |
| 300 | — | ~32–56 W |
| 500–1000 | — | ~50–125 W (thermal) |

## Modular interface

| Spec | Value |
|---|---|
| Shaft | Ø8 / bore Ø8.35 |
| Bearings | 608ZZ seats Ø21.85×7.2 |
| Hub | Ø30×10 |
| Endbell / stator bolts | **6× M3 @ R=72** (Gen-E family) |
| Brace | **4× M4 @ R≈68** (REQUIRED) |
| M3 clear | Ø3.4–3.5 |
| Heat-set | M3 inserts preferred |

## Parts to print

| File | Qty | Notes |
|---|-----|---|
| `rotor_face_a.stl` | 1 | Magnet face up; brim |
| `rotor_face_b.stl` | 1 | +22.5° pocket map |
| `stator_core.stl` | 1 | Wound-sized bays |
| `coil_former.stl` | **12** | **Wind before assembly**; thin flanges + brim |
| `gap_spacer.stl` | **12** | h=`gap_spacer_h` 1.13 |
| `endbell_front.stl` | 1 | |
| `endbell_rear.stl` | 1 | (or print front ×2) |
| `shaft_collar.stl` | 4 | |
| `fit_coupon.stl` | 1 | Print first |

One-plate: see `print-packs/one-plate/` (Kobra 3 Max ≤408×408 mm). Measured bbox **404×404 mm**.

## BOM (non-print)

| Item | Qty |
|---|-----|
| NdFeB Ø20×5 N52 | 16 |
| NdFeB Ø5×5 N52 | 48 |
| 26 AWG magnet wire | ≤323 m of ~390 m spool |
| 608ZZ bearings | 2 |
| M3 heat-set inserts + bolts | as needed |
| M4 brace rods | 4 |
| Ø8 shaft | 1 |

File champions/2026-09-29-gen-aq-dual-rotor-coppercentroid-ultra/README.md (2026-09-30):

# Gen-AQ — Dual-rotor copper-centroid ultra AFPM / wound-aware 12-coil 3φ

**PRIMARY challenger vs Gen-AN** (night 2026-09-29 ET). Dual-rotor AFPM copper-centroid Halbach; `m2m=4.71 mm` + copper-centroid Ø20 @ **R=39.0** + **205 t** + `former_web=1.25` while magnet↔wound stays **0.50 mm PASS**.

**Wound gate: PASS** — see [WOUND_ENVELOPE.md](WOUND_ENVELOPE.md).

## Wound envelope (mandatory)

| Param | Value | Notes |
|---|---|---|
| Wire | **26 AWG** | insulated OD **0.45 mm**; ~1 lb spool ≈ 390 m |
| Turns | **205** / pancake | 12×205×~0.130 m ≈ **320 m** copper (fits 1 lb) |
| fill | **0.70** | packing factor |
| layers_per_face | **2** | axial layers proud of each flange |
| `wind_build_axial` | **0.63 mm** | `2 × 0.45 × 0.7` |
| `wind_build_radial` | **0.945 mm** | `3 × 0.45 × 0.7` |
| `former_web` / `flange_t` | **1.25 / 0.60 mm** | thinner web vs AN 1.30 (LB ≥1.2) |
| `former_bare_h` | **2.45 mm** | |
| `coil_envelope_h` | **3.71 mm** | bare + 2×wind_build_axial |
| `run_clear` | **0.50 mm** | magnet → **wound** (each gap) |
| `gap_spacer_h` | **1.13 mm** | `run_clear + wind_build_axial` |
| `m2m` | **4.71 mm** | `coil_envelope_h + 2×run_clear` (**NOT** bare) |
| magnet→wound | **0.50 mm** | **PASS** both sides (≥0.5) |

Stator bays expand for wound radial outline. Explicit params in `parameters.scad`.

## Why this design

Gen-AN: Ø20 @ R=39.5, 200 t, former_web 1.30, m2m 4.76, ~15–32 W. Gen-AQ tightens copper-centroid to **R=39.0**, adds **+5 turns** (205), thins former_web to **1.25** → envelope 3.71 / m2m **4.71**, Halbach Ø5 @ {24.0,39.0,56.0}. Midpoint ~25 W vs AN ~23.5 W.

## Magnet inventory (full kit)

| Kit | Qty | Placement |
|-----|-----|---|
| Ø20×5 | **8** | Rotor A @ R=39.0 mm, 45° steps |
| Ø20×5 | **8** | Rotor B @ R=39.0 mm, offset **+22.5°** |
| Ø5×5 | **24** | Rotor A Halbach @ R={24.0,39.0,56.0} |
| Ø5×5 | **24** | Rotor B Halbach (+22.5°) |

Pockets: **Ø20.3×5.2**, **Ø5.3×5.2**.

### Polarity map

**Rotor A (+Z):** alternate N-S (even indices N toward stator).  
**Rotor B (−Z):** alternate N-S with N toward stator on even indices (flux through coils).  
**Halbach smalls:** mid circumferential; inner/outer reinforce pole tips AND extend radial coverage onto inner/outer copper.

### ⚠️ DUAL-ROTOR CLAP WARNING
Brace with **M4 rods @ R≈68** **BEFORE** seating the second magnet face. Glue one rotor completely, dry-fit wound stator + gap_spacers, brace, then approach second rotor slowly. **Wind all 12 formers before assembly.** Ultra-micro-gap (0.50 mm) leaves **minimal** forgiveness — do not skip braces. Flanges 0.60 mm / web 1.25 mm: **print with brim**, verify no warp before winding.

## Coils

- **12** pancakes — 26 AWG × 205 t; star 3φ
- Mean turn ~0.130 m → copper budget ~320 m on 1 lb 26 AWG

## Stack

```
rotor A magnet face
  └── run_clear 0.50 mm
wound copper (+Z face)
  └── coil_envelope_h 3.71 through mid stator
wound copper (−Z face)
  └── run_clear 0.50 mm
rotor B magnet face
—— m2m = 4.71 mm ——
```

## Estimated EMF / power

Method (consistent with Gen-AN night): rough AFPM scaling from copper window area × turns × B_gap × RPM. Assumptions: N52 Halbach-boosted B_gap ≈ **0.73–1.08 T** per gap (thinner m2m + tighter overlap), fill 0.70, series/3φ star, dual-face coupling where topology allows.

| RPM | Est. combined RMS | Est. matched power |
|-----|---|---|
| 120 | ~17–22 V | ~10–16 W |
| **200** | **~20–44 V** | **~16–34 W** |
| 300 | ~30–66 V | ~30–53 W |
| 500–1000 | ~50–132 V | ~48–120 W (thermal) |

## Modular interface

| Spec | Value |
|---|---|
| Shaft | Ø8 / bore Ø8.35 |
| Bearings | 608ZZ seats Ø21.85×7.2 |
| Hub | Ø30×10 |
| Endbell / stator bolts | **6× M3 @ R=72** (Gen-E family) |
| Brace | **4× M4 @ R≈68** (REQUIRED) |
| M3 clear | Ø3.4–3.5 |
| Heat-set | M3 inserts preferred |

## Parts to print

| File | Qty | Notes |
|---|-----|---|
| `rotor_face_a.stl` | 1 | Magnet face up; brim |
| `rotor_face_b.stl` | 1 | +22.5° pocket map |
| `stator_core.stl` | 1 | Wound-sized bays |
| `coil_former.stl` | **12** | **Wind before assembly**; thin flanges + brim |
| `gap_spacer.stl` | **12** | h=`gap_spacer_h` 1.13 |
| `endbell_front.stl` | 1 | |
| `endbell_rear.stl` | 1 | (or print front ×2) |
| `shaft_collar.stl` | 4 | |
| `fit_coupon.stl` | 1 | Print first |

One-plate: see `print-packs/one-plate/` (Kobra 3 Max ≤408×408 mm). Measured bbox **404×404 mm**.

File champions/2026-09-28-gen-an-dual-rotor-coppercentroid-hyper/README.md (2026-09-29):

# Gen-AN — Dual-rotor copper-centroid hyper AFPM / wound-aware 12-coil 3φ

**PRIMARY challenger vs Gen-AK** (night 2026-09-28 ET). Dual-rotor AFPM copper-centroid Halbach; `m2m=4.76 mm` + copper-centroid Ø20 @ **R=39.5** + **200 t** + `former_web=1.3` while magnet↔wound stays **0.50 mm PASS**.

**Wound gate: PASS** — see [WOUND_ENVELOPE.md](WOUND_ENVELOPE.md).

## Wound envelope (mandatory)

| Param | Value | Notes |
|---|---|---|
| Wire | **26 AWG** | insulated OD **0.45 mm**; ~1 lb spool ≈ 390 m |
| Turns | **200** / pancake | 12×200×~0.13 m ≈ **312 m** copper (fits 1 lb) |
| fill | **0.70** | packing factor |
| layers_per_face | **2** | axial layers proud of each flange |
| `wind_build_axial` | **0.63 mm** | `2 × 0.45 × 0.7` |
| `wind_build_radial` | **0.945 mm** | `3 × 0.45 × 0.7` |
| `former_web` / `flange_t` | **1.3 / 0.60 mm** | thinner web vs prior 1.40 |
| `former_bare_h` | **2.50 mm** | |
| `coil_envelope_h` | **3.76 mm** | bare + 2×wind_build_axial |
| `run_clear` | **0.50 mm** | magnet → **wound** (each gap) |
| `gap_spacer_h` | **1.13 mm** | `run_clear + wind_build_axial` |
| `m2m` | **4.76 mm** | `coil_envelope_h + 2×run_clear` (**NOT** bare) |
| magnet→wound | **0.50 mm** | **PASS** both sides (≥0.5) |

Stator bays expand for wound radial outline. Explicit params in `parameters.scad`.

## Why this design

Gen-AK: Ø20 @ R=40, 190 t, former_web 1.40, m2m 4.86, ~14–30 W. Gen-AN tightens copper-centroid to **R=39.5**, adds **+10 turns** (200), thins former_web to **1.30** → envelope 3.76 / m2m **4.76**, Halbach Ø5 @ {24.5,39.5,56.5}. Midpoint ~23.5 W vs AK ~22 W.

## Magnet inventory (full kit)

| Kit | Qty | Placement |
|-----|-----|---|
| Ø20×5 | **8** | Rotor A @ R=39.5 mm, 45° steps |
| Ø20×5 | **8** | Rotor B @ R=39.5 mm, offset **+22.5°** |
| Ø5×5 | **24** | Rotor A Halbach @ R={24.5,39.5,56.5} |
| Ø5×5 | **24** | Rotor B Halbach (+22.5°) |

Pockets: **Ø20.3×5.2**, **Ø5.3×5.2**.

### Polarity map

**Rotor A (+Z):** alternate N-S (even indices N toward stator).  
**Rotor B (−Z):** alternate N-S with N toward stator on even indices (flux through coils).  
**Halbach smalls:** mid circumferential; inner/outer reinforce pole tips AND extend radial coverage onto inner/outer copper.

### ⚠️ DUAL-ROTOR CLAP WARNING
Brace with **M4 rods @ R≈68** **BEFORE** seating the second magnet face. Glue one rotor completely, dry-fit wound stator + gap_spacers, brace, then approach second rotor slowly. **Wind all 12 formers before assembly.** Ultra-micro-gap (0.50 mm) leaves **minimal** forgiveness — do not skip braces. Flanges 0.60 mm / web 1.30 mm: **print with brim**, verify no warp before winding.

## Coils

- **12** pancakes — 26 AWG × 200 t; star 3φ
- Mean turn ~0.13 m → copper budget ~312 m on 1 lb 26 AWG

## Stack

```
rotor A magnet face
  └── run_clear 0.50 mm
wound copper (+Z face)
  └── coil_envelope_h 3.76 through mid stator
wound copper (−Z face)
  └── run_clear 0.50 mm
rotor B magnet face
—— m2m = 4.76 mm ——
```

## Estimated EMF / power

Method (consistent with Gen-AK night): rough AFPM scaling from copper window area × turns × B_gap × RPM. Assumptions: N52 Halbach-boosted B_gap ≈ **0.72–1.05 T** per gap (thinner m2m + tighter overlap), fill 0.70, series/3φ star, dual-face coupling where topology allows.

| RPM | Est. combined RMS | Est. matched power |
|-----|---|---|
| 120 | ~16–21 V | ~9–15 W |
| **200** | **~19–42 V** | **~15–32 W** |
| 300 | ~28–63 V | ~28–50 W |
| 500–1000 | ~47–126 V | ~45–115 W (thermal) |

## Modular interface

| Spec | Value |
|---|---|
| Shaft | Ø8 / bore Ø8.35 |
| Bearings | 608ZZ seats Ø21.85×7.2 |
| Hub | Ø30×10 |
| Endbell / stator bolts | **6× M3 @ R=72** (Gen-E family) |
| Brace | **4× M4 @ R≈68** (REQUIRED) |
| M3 clear | Ø3.4–3.5 |
| Heat-set | M3 inserts preferred |

## Parts to print

| File | Qty | Notes |
|---|-----|---|
| `rotor_face_a.stl` | 1 | Magnet face up; brim |
| `rotor_face_b.stl` | 1 | +22.5° pocket map |
| `stator_core.stl` | 1 | Wound-sized bays |
| `coil_former.stl` | **12** | **Wind before assembly**; thin flanges + brim |
| `gap_spacer.stl` | **12** | h=`gap_spacer_h` 1.13 |
| `endbell_front.stl` | 1 | |
| `endbell_rear.stl` | 1 | (or print front ×2) |
| `shaft_collar.stl` | 4 | |
| `fit_coupon.stl` | 1 | Print first |

One-plate: see `print-packs/one-plate/` (Kobra 3 Max ≤408×408 mm). one-plate bbox measured after plate build.

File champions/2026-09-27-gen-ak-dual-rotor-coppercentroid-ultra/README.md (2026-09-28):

# Gen-AK — Dual-rotor copper-centroid ultra AFPM / wound-aware 12-coil 3φ

**PRIMARY challenger vs Gen-AH** (night 2026-09-27 ET). Dual magnet faces across a **ultra-micro-gap** wound mid-stator (`m2m=4.86 mm` vs Gen-AH `4.96`) + **copper-centroid** magnet placement (Ø20 @ **R=40** over copper window centroid ~40) + **190 t** + thinner `former_web=1.40` while magnet↔wound stays **0.50 mm PASS**.

**Wound gate: PASS** — see [WOUND_ENVELOPE.md](WOUND_ENVELOPE.md).

## Wound envelope (mandatory)

| Param | Value | Notes |
|---|---|---|
| Wire | **26 AWG** | insulated OD **0.45 mm**; ~1 lb spool ≈ 390 m |
| Turns | **190** / pancake | 12×190×~0.132 m ≈ **301 m** copper (fits 1 lb) |
| fill | **0.70** | packing factor |
| layers_per_face | **2** | axial layers proud of each flange |
| `wind_build_axial` | **0.63 mm** | `2 × 0.45 × 0.7` |
| `wind_build_radial` | **0.945 mm** | `3 × 0.45 × 0.7` |
| `former_web` / `flange_t` | **1.40 / 0.60 mm** | thinner web vs AH 1.50 |
| `former_bare_h` | **2.60 mm** | |
| `coil_envelope_h` | **3.86 mm** | bare + 2×wind_build_axial |
| `run_clear` | **0.50 mm** | magnet → **wound** (each gap) |
| `gap_spacer_h` | **1.13 mm** | `run_clear + wind_build_axial` |
| `m2m` | **4.86 mm** | `coil_envelope_h + 2×run_clear` (**NOT** bare) |
| magnet→wound | **0.50 mm** | **PASS** both sides (≥0.5) |

Stator bays expand for wound radial outline. Explicit params in `parameters.scad`.

## Why this beats Gen-AH

Gen-AH: Ø20 @ R=41, 180 t, former_web 1.50, m2m 4.96, ~13–28 W. Gen-AK tightens copper-centroid to **R=40**, adds **+10 turns** (190), thins former_web to **1.40** → envelope 3.86 / m2m **4.86**, Halbach Ø5 @ {25,40,57} covering the copper window. Midpoint ~22 W vs AH ~20.5 W.

## Magnet inventory (full kit)

| Kit | Qty | Placement |
|-----|-----|---|
| Ø20×5 | **8** | Rotor A @ R=40 mm, 45° steps |
| Ø20×5 | **8** | Rotor B @ R=40 mm, offset **+22.5°** |
| Ø5×5 | **24** | Rotor A Halbach @ R={25,40,57} |
| Ø5×5 | **24** | Rotor B Halbach (+22.5°) |

Pockets: **Ø20.3×5.2**, **Ø5.3×5.2**. Carrier OD **156 mm**, thick **7.5 mm**.

### Polarity map

**Rotor A (+Z):** alternate N-S (even indices N toward stator).  
**Rotor B (−Z):** alternate N-S with N toward stator on even indices (flux through coils).  
**Halbach smalls:** mid circumferential; inner/outer reinforce pole tips AND extend radial coverage onto inner/outer copper.

### ⚠️ DUAL-ROTOR CLAP WARNING
Brace with **M4 rods @ R≈68** **BEFORE** seating the second magnet face. Glue one rotor completely, dry-fit wound stator + gap_spacers, brace, then approach second rotor slowly. **Wind all 12 formers before assembly.** Ultra-micro-gap (0.50 mm) leaves **minimal** forgiveness — do not skip braces. Flanges 0.60 mm / web 1.40 mm: **print with brim**, verify no warp before winding.

## Coils

- **12** pancakes on single mid stator (3φ × 4) — dual-gap each turn
- **26 AWG × 190 t**; star 3φ
- Mean turn ~0.132 m → copper budget ~301 m on 1 lb 26 AWG

## Stack

```
rotor A magnet face
  └── run_clear 0.50 mm
wound copper (+Z face)
  └── coil_envelope_h 3.86 through mid stator
wound copper (−Z face)
  └── run_clear 0.50 mm
rotor B magnet face
—— m2m = 4.86 mm ——
```

## Estimated EMF / power

Method (consistent with Gen-AH night): rough AFPM scaling from copper window area × turns × B_gap × RPM. Assumptions: N52 Halbach-boosted B_gap ≈ **0.72–1.00 T** per gap (thinner m2m + tighter overlap), fill 0.70, series/3φ star, each coil sees **two** magnet faces.

| RPM | Est. combined RMS | Est. matched power |
|-----|---|---|
| 120 | ~11–19 V | ~8–14 W |
| **200** | **~18–40 V** | **~14–30 W** |
| 300 | ~28–60 V | ~26–48 W |
| 500–1000 | ~48–130 V | ~42–110 W (thermal) |

**vs Gen-AH (~13–28 W @200, m2m 4.96):** Gen-AK targets **~14–30 W @200** — copper-centroid @ R=40 + 190 t + m2m 4.86. Midpoint favors Gen-AK as new MAX tip pending bench.

## Modular interface

| Spec | Value |
|---|---|
| Shaft | Ø8 / bore Ø8.35 |
| Bearings | 608ZZ seats Ø21.85×7.2 |
| Hub | Ø30×10 |
| Endbell / stator bolts | **6× M3 @ R=72** (Gen-E family) |
| Brace | **4× M4 @ R≈68** (REQUIRED) |
| M3 clear | Ø3.4–3.5 |
| Heat-set | M3 inserts preferred |

## Parts to print

| File | Qty | Notes |
|---|-----|---|
| `rotor_face_a.stl` | 1 | Magnet face up; brim |
| `rotor_face_b.stl` | 1 | +22.5° pocket map |
| `stator_core.stl` | 1 | Wound-sized bays |
| `coil_former.stl` | **12** | **Wind before assembly**; thin flanges + brim |
| `gap_spacer.stl` | **12** | h=`gap_spacer_h` 1.13 |
| `endbell_front.stl` | 1 | |
| `endbell_rear.stl` | 1 | (or print front ×2) |
| `shaft_collar.stl` | 4 | |
| `fit_coupon.stl` | 1 | Print first |

One-plate: see `print-packs/one-plate/` (Kobra 3 Max ≤408×408 mm asserted; **404×404**).

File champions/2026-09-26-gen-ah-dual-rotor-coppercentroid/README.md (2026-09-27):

# Gen-AH — Dual-rotor copper-centroid hypermicro AFPM / wound-aware 12-coil 3φ

**PRIMARY challenger vs Gen-AE** (night 2026-09-26 ET). Dual magnet faces across a **hyper-micro-gap** wound mid-stator (`m2m=4.96 mm` vs Gen-AE `5.00`) + **copper-centroid** magnet placement (Ø20 @ **R=41** over copper window centroid ~41) + **180 t** restore B×N while magnet↔wound stays **0.50 mm PASS**.

**Wound gate: PASS** — see [WOUND_ENVELOPE.md](WOUND_ENVELOPE.md).

## Wound envelope (mandatory)

| Param | Value | Notes |
|---|---|---|
| Wire | **26 AWG** | insulated OD **0.45 mm**; ~1 lb spool ≈ 390 m |
| Turns | **180** / pancake | 12×180×~0.136 m ≈ **294 m** copper (fits 1 lb) |
| fill | **0.70** | packing factor |
| layers_per_face | **2** | axial layers proud of each flange |
| `wind_build_axial` | **0.63 mm** | `2 × 0.45 × 0.7` |
| `wind_build_radial` | **0.945 mm** | `3 × 0.45 × 0.7` |
| `former_web` / `flange_t` | **1.50 / 0.60 mm** | print-safe mins |
| `former_bare_h` | **2.70 mm** | |
| `coil_envelope_h` | **3.96 mm** | bare + 2×wind_build_axial |
| `run_clear` | **0.50 mm** | magnet → **wound** (each gap) |
| `gap_spacer_h` | **1.13 mm** | `run_clear + wind_build_axial` |
| `m2m` | **4.96 mm** | `coil_envelope_h + 2×run_clear` (**NOT** bare) |
| magnet→wound | **0.50 mm** | **PASS** both sides (≥0.5) |

Stator bays expand for wound radial outline. Explicit params in `parameters.scad`.

## Why this beats Gen-AE

Gen-AE magnets sit at **R=54** while copper window ID18.5–OD64 has centroid ~41. Ø20 disks at R=54 only cover ~44–64, starving **inner copper**. Gen-AH places Ø20 @ **R=41** (covers ~31–51 over centroid) + Halbach Ø5 @ {26,41,58} to extend coverage onto inner/outer copper. Also run_clear 0.50 (vs 0.52) and 180 t (vs 170).

## Magnet inventory (full kit)

| Kit | Qty | Placement |
|-----|-----|---|
| Ø20×5 | **8** | Rotor A @ R=41 mm, 45° steps |
| Ø20×5 | **8** | Rotor B @ R=41 mm, offset **+22.5°** |
| Ø5×5 | **24** | Rotor A Halbach @ R={26,41,58} |
| Ø5×5 | **24** | Rotor B Halbach (+22.5°) |

Pockets: **Ø20.3×5.2**, **Ø5.3×5.2**. Carrier OD **156 mm**, thick **7.5 mm**.

### Polarity map

**Rotor A (+Z):** alternate N-S (even indices N toward stator).  
**Rotor B (−Z):** alternate N-S with N toward stator on even indices (flux through coils).  
**Halbach smalls:** mid circumferential; inner/outer reinforce pole tips AND extend radial coverage onto inner/outer copper.

### ⚠️ DUAL-ROTOR CLAP WARNING
Brace with **M4 rods @ R≈68** **BEFORE** seating the second magnet face. Glue one rotor completely, dry-fit wound stator + gap_spacers, brace, then approach second rotor slowly. **Wind all 12 formers before assembly.** Hyper-micro-gap (0.50 mm) leaves **minimal** forgiveness — do not skip braces. Flanges 0.60 mm / web 1.50 mm: **print with brim**, verify no warp before winding.

## Coils

- **12** pancakes on single mid stator (3φ × 4) — dual-gap each turn
- **26 AWG × 180 t**; star 3φ
- Mean turn ~0.136 m → copper budget ~294 m on 1 lb 26 AWG

## Stack

```
rotor A magnet face
  └── run_clear 0.50 mm
wound copper (+Z face)
  └── coil_envelope_h 3.96 through mid stator
wound copper (−Z face)
  └── run_clear 0.50 mm
rotor B magnet face
—— m2m = 4.96 mm ——
```

## Estimated EMF / power

Method (consistent with Gen-AE night): rough AFPM scaling from copper window area × turns × B_gap × RPM. Assumptions: N52 Halbach-boosted B_gap ≈ **0.70–0.98 T** per gap (thinner m2m + better overlap), fill 0.70, series/3φ star, each coil sees **two** magnet faces.

| RPM | Est. combined RMS | Est. matched power |
|-----|---|---|
| 120 | ~10–18 V | ~7–13 W |
| **200** | **~17–38 V** | **~13–28 W** |
| 300 | ~26–56 V | ~24–45 W |
| 500–1000 | ~45–120 V | ~38–100 W (thermal) |

**vs Gen-AE (~12–26 W @200, m2m 5.00):** Gen-AH targets **~13–28 W @200** — copper-centroid magnets + 180 t + m2m 4.96. Midpoint favors Gen-AH as new MAX tip pending bench.

## Modular interface

| Spec | Value |
|---|---|
| Shaft | Ø8 / bore Ø8.35 |
| Bearings | 608ZZ seats Ø21.85×7.2 |
| Hub | Ø30×10 |
| Endbell / stator bolts | **6× M3 @ R=72** (Gen-E family) |
| Brace | **4× M4 @ R≈68** (REQUIRED) |
| M3 clear | Ø3.4–3.5 |
| Heat-set | M3 inserts preferred |

## Parts to print

| File | Qty | Notes |
|---|-----|---|
| `rotor_face_a.stl` | 1 | Magnet face up; brim |
| `rotor_face_b.stl` | 1 | +22.5° pocket map |
| `stator_core.stl` | 1 | Wound-sized bays |
| `coil_former.stl` | **12** | **Wind before assembly**; thin flanges + brim |
| `gap_spacer.stl` | **12** | h=`gap_spacer_h` 1.13 |
| `endbell_front.stl` | 1 | |
| `endbell_rear.stl` | 1 | (or print front ×2) |
| `shaft_collar.stl` | 4 | |
| `fit_coupon.stl` | 1 | Print first |

One-plate: see `print-packs/one-plate/` (Kobra 3 Max ≤408×408 mm asserted).

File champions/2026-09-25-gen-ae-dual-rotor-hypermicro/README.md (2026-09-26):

# Gen-AE — Dual-rotor HYPER-MICRO copper-max AFPM / wound-aware 12-coil 3φ

**PRIMARY challenger vs Gen-AB** (night 2026-09-25 ET). Dual magnet faces across a **hyper-micro-gap** wound mid-stator (`m2m=5.00 mm` vs Gen-AB `5.22`) + larger copper window (ID 18.5–OD 64) + **170 t** restore B×N while magnet↔wound stays **0.52 mm PASS**.

**Wound gate: PASS** — see night [WOUND_ENVELOPE.md](../WOUND_ENVELOPE.md).

## Wound envelope (mandatory)

| Param | Value | Notes |
|---|---|---|
| Wire | **26 AWG** | insulated OD **0.45 mm**; ~1 lb spool ≈ 390 m |
| Turns | **170** / pancake | 12×170×~0.130 m ≈ **265 m** copper (fits 1 lb) |
| fill | **0.70** | packing factor |
| layers_per_face | **2** | axial layers proud of each flange |
| `wind_build_axial` | **0.63 mm** | `2 × 0.45 × 0.7` |
| `wind_build_radial` | **0.945 mm** | `3 × 0.45 × 0.7` |
| `former_web` / `flange_t` | **1.50 / 0.60 mm** | thinner than Gen-AB 1.6/0.60 |
| `former_bare_h` | **2.70 mm** | |
| `coil_envelope_h` | **3.96 mm** | bare + 2×wind_build_axial |
| `run_clear` | **0.52 mm** | magnet → **wound** (each gap) |
| `gap_spacer_h` | **1.15 mm** | `run_clear + wind_build_axial` |
| `m2m` | **5.00 mm** | `coil_envelope_h + 2×run_clear` (**NOT** bare) |
| magnet→wound | **0.52 mm** | **PASS** both sides (≥0.5) |

Stator bays expand for wound radial outline. Explicit params in `parameters.scad`.

## Magnet inventory (full kit)

| Kit | Qty | Placement |
|-----|-----|---|
| Ø20×5 | **8** | Rotor A @ R=54 mm, 45° steps |
| Ø20×5 | **8** | Rotor B @ R=54 mm, offset **+22.5°** |
| Ø5×5 | **24** | Rotor A Halbach @ R={42,54,66} |
| Ø5×5 | **24** | Rotor B Halbach (+22.5°) |

Pockets: **Ø20.3×5.2**, **Ø5.3×5.2**. Carrier OD **156 mm**, thick **7.5 mm**.

### Polarity map

**Rotor A (+Z):** alternate N-S (even indices N toward stator).  
**Rotor B (−Z):** alternate N-S with N toward stator on even indices (flux through coils).  
**Halbach smalls:** mid circumferential; edge smalls reinforce pole tips.  

### ⚠️ DUAL-ROTOR CLAP WARNING
Brace with **M4 rods @ R≈68** **BEFORE** seating the second magnet face. Glue one rotor completely, dry-fit wound stator + gap_spacers, brace, then approach second rotor slowly. **Wind all 12 formers before assembly.** Hyper-micro-gap (0.52 mm) leaves **less** forgiveness than Gen-AB — do not skip braces. Flanges 0.60 mm / web 1.50 mm: print with brim, verify no warp before winding.

## Coils

- **12** pancakes on single mid stator (3φ × 4) — dual-gap each turn
- **26 AWG × 170 t**; star 3φ
- Mean turn ~0.130 m → copper budget ~265 m on 1 lb 26 AWG

## Stack

```
rotor A magnet face
  └── run_clear 0.52 mm
wound copper (+Z face)
  └── coil_envelope_h 3.96 through mid stator
wound copper (−Z face)
  └── run_clear 0.52 mm
rotor B magnet face
—— m2m = 5.00 mm ——
```

## Estimated EMF / power

Method (consistent with Gen-AB night): rough AFPM scaling from copper window area × turns × B_gap × RPM. Assumptions: N52 Halbach-boosted B_gap ≈ **0.68–0.95 T** per gap (thinner m2m vs Gen-AB), fill 0.70, series/3φ star, each coil sees **two** magnet faces.

| RPM | Est. combined RMS | Est. matched power |
|-----|---|---|
| 120 | ~9–17 V | ~6–12 W |
| **200** | **~16–35 V** | **~12–26 W** |
| 300 | ~25–52 V | ~22–42 W |
| 500–1000 | ~42–110 V | ~35–95 W (thermal) |

**vs Gen-AB (~11–23 W @200, m2m 5.22):** Gen-AE targets **~12–26 W @200** — thinner envelope (5.00 vs 5.22) + more copper (170 vs 160 t) + larger window ID18.5–OD64 (~+12% area). Midpoint argument favors Gen-AE as new MAX tip pending bench.

## Modular interface

| Spec | Value |
|---|---|
| Shaft | Ø8 / bore Ø8.35 |
| Bearings | 608ZZ seats Ø21.85×7.2 |
| Hub | Ø30×10 |
| Endbell / stator bolts | **6× M3 @ R=72** (Gen-E family) |
| Brace | **4× M4 @ R≈68** (REQUIRED) |
| M3 clear | Ø3.4–3.5 |
| Heat-set | M3 inserts preferred |

## Parts to print

| File | Qty | Notes |
|---|-----|---|
| `rotor_face_a.stl` | 1 | Magnet face up; brim |
| `rotor_face_b.stl` | 1 | +22.5° pocket map |
| `stator_core.stl` | 1 | Wound-sized bays |
| `coil_former.stl` | **12** | **Wind before assembly**; thin flanges |
| `gap_spacer.stl` | **12** | h=`gap_spacer_h` |
| `endbell_front.stl` | 1 | |
| `endbell_rear.stl` | 1 | (or ×2 of front) |
| `shaft_collar.stl` | 2–4 | |
| `fit_coupon.stl` | 1 | **Print first** |

One-plate: `print-packs/one-plate/` (Kobra 3 Max ~410×410; endbell rear = duplicate print of front STL on plate).

## BOM

- 16× Ø20×5 + 48× Ø5×5 N52
- Ø8 shaft, 2–4× 608ZZ, M3 + heat-set inserts, 4× M4 brace rod
- **26 AWG** magnet wire (~1 lb)
- Optional thin steel backing behind each rotor

## Print / safety

**0.4 mm** nozzle default. PETG/ABS preferred. Walls ≥0.8 (load 1.2). **DUAL-ROTOR CLAP.** Wind all formers first. Hyper-micro-gap + 0.60 flanges + 1.50 web demand brace rods and careful first-layer adhesion.

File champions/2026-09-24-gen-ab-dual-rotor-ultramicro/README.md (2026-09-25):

# Gen-AB — Dual-rotor ULTRA-MICRO-GAP copper-max AFPM / wound-aware 12-coil 3φ

**PRIMARY challenger vs Gen-Y** (night 2026-09-24 ET). Dual magnet faces across an **ultra-micro-gap** wound mid-stator (`m2m=5.22 mm` vs Gen-Y `5.76`) + larger copper window (ID 20–OD 62) + 160 t restore B×N while magnet↔wound stays **0.58 mm PASS**.

**Wound gate: PASS** — see night [WOUND_ENVELOPE.md](../WOUND_ENVELOPE.md).

## Wound envelope (mandatory)

| Param | Value | Notes |
|---|---|---|
| Wire | **26 AWG** | insulated OD **0.45 mm**; ~1 lb spool ≈ 390 m |
| Turns | **160** / pancake | 12×160×~0.125 m ≈ **240 m** copper (fits 1 lb) |
| fill | **0.70** | packing factor |
| layers_per_face | **2** | axial layers proud of each flange |
| `wind_build_axial` | **0.63 mm** | `2 × 0.45 × 0.7` |
| `wind_build_radial` | **0.945 mm** | `3 × 0.45 × 0.7` |
| `former_web` / `flange_t` | **1.6 / 0.60 mm** | thinner than Gen-Y 1.8/0.70 (print-safe mins) |
| `former_bare_h` | **2.8 mm** | |
| `coil_envelope_h` | **4.06 mm** | bare + 2×wind_build_axial |
| `run_clear` | **0.58 mm** | magnet → **wound** (each gap) |
| `gap_spacer_h` | **1.21 mm** | `run_clear + wind_build_axial` |
| `m2m` | **5.22 mm** | `coil_envelope_h + 2×run_clear` (**NOT** bare) |
| magnet→wound | **0.58 mm** | **PASS** both sides (≥0.5) |

Stator bays expand for wound radial outline. Explicit params in `parameters.scad`.

## Magnet inventory (full kit)

| Kit | Qty | Placement |
|-----|-----|---|
| Ø20×5 | **8** | Rotor A @ R=52 mm, 45° steps |
| Ø20×5 | **8** | Rotor B @ R=52 mm, offset **+22.5°** |
| Ø5×5 | **24** | Rotor A Halbach @ R={40,52,64} |
| Ø5×5 | **24** | Rotor B Halbach (+22.5°) |

Pockets: **Ø20.3×5.2**, **Ø5.3×5.2**. Carrier OD **152 mm**, thick **7.5 mm**.

### Polarity map

**Rotor A (+Z):** alternate N-S (even indices N toward stator).  
**Rotor B (−Z):** alternate N-S with N toward stator on even indices (flux through coils).  
**Halbach smalls:** mid circumferential; edge smalls reinforce pole tips.  

### ⚠️ DUAL-ROTOR CLAP WARNING
Brace with **M4 rods @ R≈68** **BEFORE** seating the second magnet face. Glue one rotor completely, dry-fit wound stator + gap_spacers, brace, then approach second rotor slowly. **Wind all 12 formers before assembly.** Ultra-micro-gap (0.58 mm) leaves **less** forgiveness than Gen-Y — do not skip braces. Flanges 0.60 mm: print with brim, verify no warp before winding.

## Coils

- **12** pancakes on single mid stator (3φ × 4) — dual-gap each turn
- **26 AWG × 160 t**; star 3φ
- Mean turn ~0.125 m → copper budget ~240 m on 1 lb 26 AWG

## Stack

```
rotor A magnet face
  └── run_clear 0.58 mm
wound copper (+Z face)
  └── coil_envelope_h 4.06 through mid stator
wound copper (−Z face)
  └── run_clear 0.58 mm
rotor B magnet face
—— m2m = 5.22 mm ——
```

## Estimated EMF / power

Method (consistent with Gen-Y night): rough AFPM scaling from copper window area × turns × B_gap × RPM. Assumptions: N52 Halbach-boosted B_gap ≈ **0.65–0.92 T** per gap (thinner m2m vs Gen-Y), fill 0.70, series/3φ star, each coil sees **two** magnet faces.

| RPM | Est. combined RMS | Est. matched power |
|-----|---|---|
| 120 | ~8–15 V | ~5–10 W |
| **200** | **~15–32 V** | **~11–23 W** |
| 300 | ~23–48 V | ~20–38 W |
| 500–1000 | ~38–100 V | ~30–85 W (thermal) |

**vs Gen-Y (~10–21 W @200, m2m 5.76):** Gen-AB targets **~11–23 W @200** — thinner envelope (5.22 vs 5.76) + more copper (160 vs 150 t) + larger window ID20–OD62 (~+9% area). Midpoint argument favors Gen-AB as new MAX tip pending bench.

## Modular interface

| Spec | Value |
|---|---|
| Shaft | Ø8 / bore Ø8.35 |
| Bearings | 608ZZ seats Ø21.85×7.2 |
| Hub | Ø30×10 |
| Endbell / stator bolts | **6× M3 @ R=72** (Gen-E family) |
| Brace | **4× M4 @ R≈68** (REQUIRED) |
| M3 clear | Ø3.4–3.5 |
| Heat-set | M3 inserts preferred |

## Parts to print

| File | Qty | Notes |
|---|-----|---|
| `rotor_face_a.stl` | 1 | Magnet face up; brim |
| `rotor_face_b.stl` | 1 | +22.5° pocket map |
| `stator_core.stl` | 1 | Wound-sized bays |
| `coil_former.stl` | **12** | **Wind before assembly**; thin flanges |
| `gap_spacer.stl` | **12** | h=`gap_spacer_h` |
| `endbell_front.stl` | 1 | |
| `endbell_rear.stl` | 1 | (or ×2 of front) |
| `shaft_collar.stl` | 2–4 | |
| `fit_coupon.stl` | 1 | **Print first** |

One-plate: `print-packs/one-plate/` (Kobra 3 Max ~410×410; endbell rear = duplicate print of front STL on plate).

## BOM

- 16× Ø20×5 + 48× Ø5×5 N52
- Ø8 shaft, 2–4× 608ZZ, M3 + heat-set inserts, 4× M4 brace rod
- **26 AWG** magnet wire (~1 lb)
- Optional thin steel backing behind each rotor

## Print / safety

**0.4 mm** nozzle default. PETG/ABS preferred. Walls ≥0.8 (load 1.2). **DUAL-ROTOR CLAP.** Wind all formers first. Ultra-micro-gap + 0.60 flanges demand brace rods and careful first-layer adhesion.

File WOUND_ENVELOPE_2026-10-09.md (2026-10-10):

# 2026-10-09 nightly — physics_scorer ranking (Gen-BR / BS / BT)

Scorer: `/workspace/generators/tools/physics_scorer/score_kit score <kit> --out <kit> --back-iron` (all three kits ship mild-steel back-iron discs, so the headline is the `--back-iron` number = the scorer's **optimistic image-method upper bound**; the air-core number without `--back-iron` is recorded next to it).
`score_kit sanity`: single Ø20×5 N52 surface Bz 0.3198 T (analytic 0.3198) → PASS.

Champion to beat: **Gen-BO** (`/workspace/generators/2026-10-07/gen-bo-dual-rotor-flushseat-6coil-widelip`) **5.497 W** matched-load @ 200 RPM with `--back-iron` (air-core what-if 2.713 W).

## Ranking (PASS kits by matched-load W @ 200 RPM, `--back-iron`)

| Rank | Kit | P matched (steel) | P air-core | Voc rms/ph | R Ω/ph | Turns/coil | Bz pk/mean T | Coils/poles | Wire m | Steel | Plate mm | Verdict |
|---|---|---|---|---|---|---|---|---|---|---|---|---|
| 1 | **Gen-BR** `gen-br-dual-rotor-bo-retrofit-tight-o5` | **5.507 W** | 2.727 W | 11.01 | 16.51 | 595 | 0.540/0.104 | 6c/8p | 370 | 2× Ø134 × 4.76 mm (3/16") mild-steel discs | 407.9×408.0 | PASS / geom PASS |
| 2 | **Gen-BS** `gen-bs-dual-rotor-compact-r48-wiresaver` | **5.406 W** | 2.708 W | 10.71 | 15.90 | 612 | 0.542/0.111 | 6c/8p | 356 | 2× Ø134 × 4.76 mm (3/16") mild-steel discs | 407.9×408.0 | PASS / geom PASS |
| 3 | **Gen-BT** `gen-bt-dual-rotor-9coil-r53-smooth` | **4.481 W** | 2.181 W | 9.92 | 16.47 | 521 | 0.489/0.159 | 9c/8p | 369 | 2× Ø140 × 4.76 mm (3/16") mild-steel discs | 407.9×408.0 | PASS / geom PASS |

## Design ideas

- **Gen-BR**: Rotor-only swap for Gen-BO: the diametric Ø5 assists move from ±7 mm to ±6.2 mm around the R50 pole ring (R43.8/50/56.2), the closest spacing that still leaves a 0.9 mm printed web between Ø5.3 pockets (rule ≥0.8). Everything else — bobbins, 595 t windings, stator, Ø134 steel — is Gen-BO. Tonight's 138-row refine scan (ring radius 49–51, coil radii ±0.5, build ±0.4, copper height 7.9–8.3) found nothing better: the 8p/6c flush-seat family is saturated under the ~370 m wire budget, so this is a hair-width step (about +0.2 % over Gen-BO), not a breakthrough.
- **Gen-BS**: Pull the whole machine 2 mm inward: poles at R48 (was R50) with 26–68 mm bobbins and an 18.5 mm build. Shorter mean turn length lets each coil hold 612 turns on about 356 m of copper — ~14 m less than Gen-BO, which leaves real slack on a ~390 m spool for leads, a re-wind or a short spool — for about 1.7 % less power. Same Ø134 steel discs as Gen-BO.
- **Gen-BT**: The low-cogging 8-pole / 9-coil line (winding factor 0.945) moved to a larger R53 pole ring with 36–70 mm bobbins and a 13.5 mm build, the best 9-coil row in tonight's scans (Gen-BQ was R52 / 35–70 / 12.6). Smoother to spin by hand and quieter, but still well below 6 coils under the wire budget.

## Ø5 assists on/off (scorer, `--back-iron`)

- Gen-BR: 5.507 W with diametric Ø5 vs 5.120 W without (+7.6 %)
- Gen-BS: 5.406 W with diametric Ø5 vs 4.997 W without (+8.2 %)
- Gen-BT: 4.481 W with diametric Ø5 vs 4.241 W without (+5.7 %)

## Dense-wind dependence (scorer, `--back-iron --fill 0.60` = same windows, fewer turns)

- Gen-BR: 5.507 W at fill 0.65 vs 5.088 W if only fill 0.60 is reached
- Gen-BS: 5.406 W at fill 0.65 vs 4.988 W if only fill 0.60 is reached
- Gen-BT: 4.481 W at fill 0.65 vs 4.133 W if only fill 0.60 is reached

## What the scans showed (`_design_scan/`, wire ≤ 370 m, all `--back-iron`)

- **The 8p/6c flush-seat family is saturated.** A 138-row refine around Gen-BO (pole ring R49/50/51 with the Ø5 map following it,
  bobbin inner/outer radius ±0.5 mm, radial build 17.6–18.4 mm, copper height 7.9–8.3 mm) found no row more than +0.02 % above Gen-BO.
  Every extra turn either needs more than the ~370 m wire budget or sits in weaker field.
- **Tightest legal Ø5 map:** ±6.2 mm (R43.8/50/56.2) leaves a 0.9 mm web between Ø5.3 pockets (rule ≥ 0.8) and is the only change that
  scored above Gen-BO in the scan (5.498 vs 5.488 scan-resolution) — built as Gen-BR, a rotor-only swap.
- **Taller, thinner copper loses:** 8.4–9.4 mm copper with 15.5–17 mm build: best 5.405 W (the extra gap costs more field than the turns gain).
- **Smaller ring saves copper:** poles at R48 with 26–68 mm bobbins: 5.410 W on only ≈356 m (R47: 5.38 W; R46 and 65–66.5 mm outer radius worse) —
  built as Gen-BS for wire margin on a ~390 m spool.
- **9 coils:** best R53 / 36–70 mm / 13.5 build 4.478 W (Gen-BQ 4.420 W) — built as Gen-BT for smooth torque; 9 coils still lose to 6 under the wire budget.
- **Not modellable honestly tonight (not built):** single-phase 8-coil layouts (scorer requires balanced 3φ), stator-side steel, axial Ø5 pole
  extenders, trapezoid coils. To go meaningfully past ~5.5 W the next levers are outside tonight's fixed kit: more copper (a second spool),
  higher RPM, or thicker magnets.

## Champion

**Gen-BR** at **5.507 W** (`--back-iron`, air-core 2.727 W) — BEATS Gen-BO 5.497 W (1.002×, same scoring mode).

Pushed Gen-BR to [lucidlooney2030/MAX-Versions](https://github.com/lucidlooney2030/MAX-Versions) @d0e9d2b as champion (CHAMPION.md updated; Gen-BS/BT as runners).

Archive: `/workspace/generators/2026-10-09-generators.tar.gz`

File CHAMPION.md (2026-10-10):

# Current champion — MAX-Versions

**As of 2026-10-09-night (ET): Gen-BR dual-rotor Gen-BO rotor retrofit, tightest legal Ø5 map — physics_scorer MAX tip.**

Path: [`champions/2026-10-09-gen-br-dual-rotor-bo-retrofit-tight-o5/`](champions/2026-10-09-gen-br-dual-rotor-bo-retrofit-tight-o5/)  
Print pack: [`print-packs/gen-br-dual-rotor-bo-retrofit-tight-o5/`](print-packs/gen-br-dual-rotor-bo-retrofit-tight-o5/) (one-plate STL + parts + `laser-cut/steel_backiron_disc.dxf`)

Gen-BR edges out Gen-BO on **honest** matched-load watts from `physics_scorer` (magpylib, PLA = air, N52 Br 1.43 T,
26 AWG @20 °C, steel back-iron via `--back-iron` image method = optimistic upper bound; same mode as Gen-BO):

| Metric @ 200 RPM | Gen-BR (new) | Gen-BO (prior champion) |
|---|---|---|
| Matched-load P (3φ V²/4R) | **5.507 W** | 5.497 W |
| Voc rms/phase | **11.01 V** | 11.00 V |
| R_phase @20 °C | **16.51 Ω** | 16.51 Ω |
| Turns fit / coil | **595** (fill 0.65) | 595 (fill 0.65) |
| Bz peak / mean window | **0.540 / 0.104 T** | 0.540 / 0.104 T |
| Topology | dual_rotor 8p/6c + 2× Ø134 × 4.76 mm steel | same |
| Copper | 370 m | 370 m |
| Air-core what-if (no `--back-iron`) | 2.727 W | 2.713 W |
| Verdict | **PASS** (geometry check PASS) | PASS |

That is **+0.2 %** — a hair. The 8p/6c flush-seat family is saturated under the ~370 m wire budget (a 197-row scan tonight found nothing bigger).

## What changed

Only the two rotor carriers: the diametric Ø5 assists move from ±7 mm to **±6.2 mm** around the R50 pole ring (R43.8/50/56.2), the closest
spacing that still leaves a 0.9 mm printed web between Ø5.3 pockets (rule ≥ 0.8). Bobbins, 595 t windings, stator, gap sleeve, endbells,
standoffs and the Ø134 × 4.76 mm steel discs/DXF are identical to Gen-BO — an existing Gen-BO upgrades by printing two rotors.
Ø5 assists: +7.6 % vs none (5.120 W without). Fill 0.60 what-if: 5.088 W. Clocking 0°, D-flat + notch, flip-symmetric holes, windable bobbins,
magnet→wound envelope 0.50 mm, one-plate 407.9 × 408.0 mm.

Night scorecard: [`WOUND_ENVELOPE_2026-10-09.md`](WOUND_ENVELOPE_2026-10-09.md) (= SCORECARD).

## Runners (same night, also PASS)

- Gen-BS compact R48 wire-saver — `champions/runners-2026-10-09/gen-bs-dual-rotor-compact-r48-wiresaver/` (**5.406 W**, 10.71 V rms/ph, air-core 2.708 W; only 356 m copper, 14 m spare on a ~390 m spool; same Ø134 steel)
- Gen-BT 8p/9c smooth-torque R53 — `champions/runners-2026-10-09/gen-bt-dual-rotor-9coil-r53-smooth/` (**4.481 W**, 9.92 V rms/ph, air-core 2.181 W; new Ø140 × 4.76 mm steel)

## Assembly warnings

- **Clap hazard** (steel-backed N52 across a 10.7 mm gap): use the 4 temporary M4 jack rods (R18) and lower rotor B by the nuts before seating the second magnet face.
- Remove temporary braces and gap shims before spinning; shim against the **magnet faces** (flush seat — caliper the magnets first).
- Brim on 0.8 mm flanges / 1.2 mm stator webs (and the 0.9 mm Ø5 pocket webs on the rotors).
- Ø5 assists must be **diametrically** magnetised, glued tangentially (axial Ø5 are not counted).
- Wind bobbins before assembly, dense and layer-by-layer (61.6 m per coil); do not raise turns. 370 m of a ~390 m spool — very little spare (Gen-BS leaves 14 m).

## Prior champion

Gen-BO dual-rotor flush-seat 6-coil wide-lip — `champions/2026-10-07-gen-bo-dual-rotor-flushseat-6coil-widelip/` (5.497 W). Superseded by Gen-BR 5.507 W.
Gen-BL dual-rotor steel-seat 6-coil dense-wind — `champions/2026-10-06-gen-bl-dual-rotor-steelseat-6coil-densewind/` (5.299 W). Superseded by Gen-BO 5.497 W.
Gen-BF dual-rotor steel-seat 6-coil tall-copper — `champions/2026-10-04-gen-bf-dual-rotor-steelseat-6coil-tallcopper/` (4.380 W). Superseded by Gen-BL 5.299 W.
Gen-BE dual-rotor backiron 9-coil mega — `champions/2026-10-03-gen-be-dual-rotor-backiron-9coil-mega/` (1.684 W). Superseded by Gen-BF 4.380 W.
Corrected Gen-BA mid-rotor (0.615 W) remains the air-core mid baseline in the generators workspace `2026-10-02-fixed/`.

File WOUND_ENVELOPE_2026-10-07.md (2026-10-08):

# 2026-10-07 nightly — physics_scorer ranking (Gen-BO / BP / BQ)

Scorer: `/workspace/generators/tools/physics_scorer/score_kit score <kit> --out <kit> --back-iron` (all three kits ship mild-steel back-iron discs, so the headline is the `--back-iron` number = the scorer's **optimistic image-method upper bound**; the air-core number without `--back-iron` is recorded next to it).
`score_kit sanity`: single Ø20×5 N52 surface Bz 0.3198 T (analytic 0.3198) → PASS.

Champion to beat: **Gen-BL** (`/workspace/generators/2026-10-06/gen-bl-dual-rotor-steelseat-6coil-densewind`) **5.299 W** matched-load @ 200 RPM with `--back-iron` (air-core what-if 2.570 W).

## Ranking (PASS kits by matched-load W @ 200 RPM, `--back-iron`)

| Rank | Kit | P matched (steel) | P air-core | Voc rms/ph | R Ω/ph | Turns/coil | Bz pk/mean T | Coils/poles | Wire m | Steel | Plate mm | Verdict |
|---|---|---|---|---|---|---|---|---|---|---|---|---|
| 1 | **Gen-BO** `gen-bo-dual-rotor-flushseat-6coil-widelip` | **5.497 W** | 2.713 W | 11.00 | 16.51 | 595 | 0.540/0.104 | 6c/8p | 370 | 2× Ø134 × 4.76 mm (3/16") mild-steel discs | 407.9×408.0 | PASS / geom PASS |
| 2 | **Gen-BP** `gen-bp-dual-rotor-flushseat-bl-retrofit` | **5.460 W** | 2.688 W | 10.92 | 16.39 | 566 | 0.540/0.104 | 6c/8p | 367 | 2× Ø134 × 4.76 mm (3/16") mild-steel discs | 407.9×408.0 | PASS / geom PASS |
| 3 | **Gen-BQ** `gen-bq-dual-rotor-flushseat-9coil-widelip` | **4.420 W** | 2.150 W | 9.80 | 16.30 | 486 | 0.489/0.156 | 9c/8p | 365 | 2× Ø138 × 4.76 mm (3/16") mild-steel discs | 407.9×408.0 | PASS / geom PASS |

## Design ideas

- **Gen-BO**: Flush seat + wider copper + tight assists: the magnets sit on the steel in 5.00 mm through-pockets (carrier = magnet height, recess 0 instead of 0.10 mm), so the magnet faces are 0.2 mm closer while still exactly 0.50 mm from the wound envelope; the bobbin lip beyond the copper is trimmed 1.0 → 0.8 mm (still the 0.8 mm wall minimum, stator web still 1.2 mm), which widens each copper sector by ~0.6° on 28–70 mm × 18.0 mm-build bobbins; and the diametric Ø5 assists are pulled in to R43/50/57 (±7 mm) where they add most flux under the copper. Same Ø134 × 4.76 mm steel discs as Gen-BL.
- **Gen-BP**: Cheapest upgrade of the champion: keep Gen-BL's wound bobbins, stator, gap sleeve, endbells and Ø134 steel, and print only two new rotor carriers — 5.00 mm thick (flush magnet seat, recess 0 instead of 0.10 mm, magnet→wound envelope still 0.50 mm) with the diametric Ø5 assists moved from R40/50/60 to R43/50/57. Modular: the rotor is the only swapped module.
- **Gen-BQ**: Smooth-torque 8-pole / 9-coil line (winding factor 0.945, much lower cogging than 6-coil) with tonight's gap levers: flush 5.00 mm through-pocket seat, 0.8 mm bobbin lip (wider 35–70 mm sectors) and a ±8 mm Ø5 map at R44/52/60, on the Gen-BN Ø138 × 4.76 mm steel. Improves Gen-BN 4.166 W but 9 coils still lose to 6 coils under the wire budget.

## Ø5 assists on/off (scorer, `--back-iron`)

- Gen-BO: 5.497 W with diametric Ø5 vs 5.120 W without (+7.4 %)
- Gen-BP: 5.460 W with diametric Ø5 vs 5.087 W without (+7.3 %)
- Gen-BQ: 4.420 W with diametric Ø5 vs 4.178 W without (+5.8 %)

## Dense-wind dependence (scorer, `--back-iron --fill 0.60` = same windows, fewer turns)

- Gen-BO: 5.497 W at fill 0.65 vs 5.079 W if only fill 0.60 is reached
- Gen-BP: 5.460 W at fill 0.65 vs 5.032 W if only fill 0.60 is reached
- Gen-BQ: 4.420 W at fill 0.65 vs 4.080 W if only fill 0.60 is reached

## What the scans showed (`_design_scan/`, wire ≤ 370 m, all `--back-iron`)

- **Flush magnet seat is tonight's lever (+2.2 %).** Last night's through-pockets were 5.10 mm deep for 5.00 mm magnets, so each magnet
  face sat 0.10 mm below the rotor face and 0.60 mm from the wound envelope (rule: ≥ 0.50). Printing the carrier exactly magnet-height
  (5.00 mm, magnets still sitting on the steel) removes that 0.2 mm of total gap with the clearance still at the 0.50 mm minimum:
  Gen-BL geometry 5.296 → 5.415 W in the scan (t1 reference rows). Needs calipered magnets (README).
- **0.8 mm bobbin lip (+0.6 %).** The flange lip beyond the copper was 1.0 mm; 0.8 mm still meets the 0.8 mm wall rule and keeps the
  1.2 mm stator web, and widens each 6-coil copper sector 52.7° → 53.2°: best flush + lip row 5.447 W (t1, 28–70 mm × 18.0 build).
- **Tighter diametric Ø5 map (+0.7 %).** Pulling the three assists per gap from R40/50/60 (±10) to R43/50/57 (±7) puts their flux under
  the copper's high-turn-density middle: 5.447 → 5.488 W (t3/t4). ±6 (R44/50/56) would leave a 0.7 mm pocket web (< 0.8 mm rule) and
  was not used; asymmetric maps like R42/48/58 score 5.481 W but also break the 0.8 mm web rule.
- **Coil/pole ratio — 6 coils still wins under the wire budget.** 8p/12c (small sector bobbins, short MLT): best 3.20 W (t2) — the narrow
  sectors waste window on webs/lips and the inradius limit caps the build at ≈10.7 mm. 8p/3c: 0.10 W (each 120° coil spans 2⅔ poles and
  its flux almost cancels). 8p/9c with tonight's levers: 4.43 W (vs Gen-BN 4.17 W) — built as Gen-BQ for its smoother torque.
- **4-pole with stacked Ø20 (10 mm poles, same 16 magnets):** 2.3–2.5 W and over the wire budget (t2) — thicker poles do not make up for
  half the electrical frequency.
- **Not modellable honestly tonight (not built):** trapezoid/parallel-web coils (the scorer only integrates radial-sided sectors, so a
  trapezoid would be scored as something it is not), Ø5 stacked on/around the Ø20 as axial pole extenders (the scorer only counts
  diametric Ø5 between poles), 16-pole layouts (need 32 Ø20 for a dual rotor; Ø5 axial clusters as poles are not modelled), steel pole
  shoes / steel on a mid rotor. Steel thickness does not change the image-method score; it is sized by `_build/steel_flux.py` instead.
- **Series vs parallel** still does not change matched-load watts (P = Σ V²/4R); it only moves the matching point.

## Champion

**Gen-BO** at **5.497 W** (`--back-iron`, air-core 2.713 W) — BEATS Gen-BL 5.299 W (1.037×, same scoring mode).

Pushed to lucidlooney2030/MAX-Versions (see CHAMPION.md).

Archive: `/workspace/generators/2026-10-07-generators.tar.gz`

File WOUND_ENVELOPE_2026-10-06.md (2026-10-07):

# 2026-10-06 nightly — physics_scorer ranking (Gen-BL / BM / BN)

Scorer: `/workspace/generators/tools/physics_scorer/score_kit score <kit> --out <kit> --back-iron` (all three kits ship mild-steel back-iron discs, so the headline is the `--back-iron` number = the scorer's **optimistic image-method upper bound**; the air-core number without `--back-iron` is recorded next to it).
`score_kit sanity`: single Ø20×5 N52 surface Bz 0.3198 T (analytic 0.3198) → PASS.

Champion to beat: **Gen-BF** (`/workspace/generators/2026-10-04/gen-bf-dual-rotor-steelseat-6coil-tallcopper`) **4.380 W** matched-load @ 200 RPM with `--back-iron` (air-core what-if 2.152 W).

## Ranking (PASS kits by matched-load W @ 200 RPM, `--back-iron`)

| Rank | Kit | P matched (steel) | P air-core | Voc rms/ph | R Ω/ph | Turns/coil | Bz pk/mean T | Coils/poles | Wire m | Steel | Plate mm | Verdict |
|---|---|---|---|---|---|---|---|---|---|---|---|---|
| 1 | **Gen-BL** `gen-bl-dual-rotor-steelseat-6coil-densewind` | **5.299 W** | 2.570 W | 10.76 | 16.39 | 566 | 0.532/0.102 | 6c/8p | 367 | 2× Ø134 × 4.76 mm (3/16") mild-steel discs | 407.9×408.0 | PASS / geom PASS |
| 2 | **Gen-BM** `gen-bm-dual-rotor-steelseat-6coil-lowgap-quarterinch` | **5.189 W** | 2.503 W | 10.43 | 15.72 | 562 | 0.547/0.103 | 6c/8p | 352 | 2× Ø138 × 6.35 mm (1/4") mild-steel discs | 407.9×408.0 | PASS / geom PASS |
| 3 | **Gen-BN** `gen-bn-dual-rotor-steelseat-9coil-densewind` | **4.166 W** | 1.994 W | 9.45 | 16.06 | 486 | 0.482/0.158 | 9c/8p | 360 | 2× Ø138 × 4.76 mm (3/16") mild-steel discs | 407.9×408.0 | PASS / geom PASS |

## Design ideas

- **Gen-BL**: Dense-wind, smaller gap: the wire budget (not the window) limits these machines, so the same ~367 m of 26 AWG is laid layer-by-layer at fill 0.65 into a SHORTER 8.1 mm window (vs 9.0 mm on Gen-BI) with a 17.1 mm build on 29–71 mm sector bobbins. That shrinks the magnet-to-magnet gap 11.6 → 10.7 mm, so every turn sees more flux. Rotors, Ø5 tight-assist map and Ø134 × 4.76 mm steel are identical to Gen-BI (modular: swap in new bobbins, stator, gap sleeve and endbells).
- **Gen-BM**: Lowest-gap pancake: Ø20 ring at R52 (Ø5 assists R42/52/62) with low-profile 7.65 mm dense-wound copper and an 18 mm radial build on wide 29–71 mm sector bobbins — the smallest magnet gap of the series (10.25 mm) — on thick 1/4" (6.35 mm) steel so the higher flux per pole stays well clear of saturation.
- **Gen-BN**: 8-pole / 9-coil (winding factor 0.945, smoother torque and lower cogging than 6-coil) on the Gen-BK R52 rotors/steel, re-wound dense at fill 0.65 with 9.45 mm copper on 35–70 mm bobbins — more turns per metre than Gen-BK at the same ~360 m wire.

## Ø5 assists on/off (scorer, `--back-iron`)

- Gen-BL: 5.299 W with diametric Ø5 vs 4.975 W without (+6.5 %)
- Gen-BM: 5.189 W with diametric Ø5 vs 4.885 W without (+6.2 %)
- Gen-BN: 4.166 W with diametric Ø5 vs 3.970 W without (+4.9 %)

## Dense-wind dependence (scorer, `--back-iron --fill 0.60` = same windows, fewer turns)

- Gen-BL: 5.299 W at fill 0.65 vs 4.884 W if only fill 0.60 is reached
- Gen-BM: 5.189 W at fill 0.65 vs 4.793 W if only fill 0.60 is reached
- Gen-BN: 4.166 W at fill 0.65 vs 3.846 W if only fill 0.60 is reached

## What the scans showed (`_design_scan/`, wire ≤ 370 m, all `--back-iron`)

- **Dense winding is tonight's lever.** The wire budget (≈370 m), not the bobbin window, limits these machines. Winding the same copper
  layer-by-layer at fill 0.65 (the scorer's cap; 0.60 was used through 10-05) packs it into a shorter window, so the magnet gap shrinks
  and every turn sees more flux: best 8p/6c row 4.996 W @ fill 0.60 (9.0 mm copper, = Gen-BI) → 5.27–5.31 W @ fill 0.65 with 7.65–8.1 mm
  copper (t1/t2), **+6 %** at the same wire length. The kits' `--fill 0.60` what-ifs below show what a looser hand wind gives.
- **The 8p/6c family has plateaued at ≈5.3 W** under this wire budget: RL 50 vs 52 vs 54, rin 26–32, rout 70–75, copper 6.75–8.55 mm and
  Ø5 radii ±9–11 mm all land within ±1 % of each other (t2/t3). Lower copper (7.2 mm) or R54 rings do not help.
- **8p/9c dense** improves Gen-BK's 3.86 W to ≈4.18–4.26 W (t2), still below 8p/6c.
- **6-pole** (12 Ø20, 6p/9c): 2.5–2.7 W (t3) — fewer magnets and lower frequency lose more than the reduced leakage gains.
- **Series vs parallel** coil connection does not change matched-load watts (P = Σ V²/4R; paralleling divides V by m and R by m²), it
  only moves the matching point, so it is not a power lever; series is kept for rectifier headroom.
- **Multi-stator / steel-mirror ideas (not built):** the midplane of an N-facing-S dual rotor is already a flux-symmetry plane, so splitting the gap
  into two single-sided machines with a steel mirror in the middle gives (ideally) the same field with twice the flanges/clearances — a loss.
  A 3-rotor / 2-stator stack needs 24 Ø20 for 8 poles (we have 16) and the scorer cannot model steel on a mid rotor.

## Champion

**Gen-BL** at **5.299 W** (`--back-iron`, air-core 2.570 W) — BEATS Gen-BF 4.380 W (1.210×, same scoring mode).

Pushed to lucidlooney2030/MAX-Versions (champions/2026-10-06-gen-bl-dual-rotor-steelseat-6coil-densewind, runners-2026-10-06, print-packs, CHAMPION.md, WOUND_ENVELOPE_2026-10-06.md) — commit "2026-10-06 night: Gen-BL ... dethrones Gen-BF".

Archive: `/workspace/generators/2026-10-06-generators.tar.gz`

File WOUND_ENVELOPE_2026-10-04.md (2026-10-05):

# 2026-10-04 nightly — physics_scorer ranking (Gen-BF / BG / BH)

Scorer: `/workspace/generators/tools/physics_scorer/score_kit score <kit> --out <kit> --back-iron` (all three kits ship two buyable 3 mm mild-steel discs).
`score_kit sanity`: single Ø20×5 N52 surface Bz 0.3198 T (analytic 0.3198) → PASS.

Champion to beat: **Gen-BE** (`/workspace/generators/2026-10-03/gen-be-dual-rotor-backiron-9coil-mega`) **1.684 W** matched-load @ 200 RPM.

## Ranking (PASS kits by matched-load W @ 200 RPM)

| Rank | Kit | P matched | Voc rms/ph | R Ω/ph | Turns/coil | Bz pk/mean T | Topology | Coils/poles | Wire m | Steel | Plate mm | Verdict |
|---|---|---|---|---|---|---|---|---|---|---|---|---|
| 1 | **Gen-BF** `gen-bf-dual-rotor-steelseat-6coil-tallcopper` | **4.380 W** | 9.04 | 14.00 | 571 | 0.474/0.123 | dual_rotor | 6c/8p | 314 | 2× Ø127×3 | 408.5×409.0 | PASS / geom PASS |
| 2 | **Gen-BG** `gen-bg-dual-rotor-steelseat-9coil-tallcopper` | **3.176 W** | 6.97 | 11.47 | 364 | 0.472/0.193 | dual_rotor | 9c/8p | 257 | 2× Ø135×3 | 409.0×409.0 | PASS / geom PASS |
| 3 | **Gen-BH** `gen-bh-dual-rotor-steelseat-4pole-doublestack` | **1.843 W** | 5.92 | 14.27 | 571 | 0.578/0.152 | dual_rotor | 6c/4p | 320 | 2× Ø126×3 | 408.5×409.0 | PASS / geom PASS |

## Design ideas

- **Gen-BF**: 8-pole / 6-coil dual rotor with big 51.5 deg sector coils and TALL 9.9 mm copper, magnets seated directly on 3 mm steel back-iron discs (through-pockets) so the field stays high across a wide gap.
- **Gen-BG**: 8-pole / 9-coil dual rotor (best winding factor 0.945) pushed out to RL 46 with 9.9 mm tall copper on steel-seated magnets; 3 smaller coils per phase and less wire (257 m) than 6-coil.
- **Gen-BH**: All 16 O20 magnets used as 8 double-height (10 mm) poles: 4-pole / 6-coil dual rotor on 3 mm steel, tall 9.9 mm copper; O5 assists left out because the scorer shows they do not help this pole layout.

## What the scans showed (`_design_scan/`, scan_bi.py, all with --back-iron, wire ≤ 370 m)

- **Tall copper is the big lever once steel is in.** With steel images the gap field falls slowly with gap, so copper volume wins:
  Gen-BE geometry with through-pockets at 3.6 mm web → 1.78 W; same coil at 7.2 mm web → 2.27 W (quick check). Optimum web ≈ 9.9–10.8 mm; beyond that wire budget / Bz drop flatten it.
- **Coil count:** 8p/6c (big 51° sectors) ≫ 8p/9c ≫ 8p/12c at equal copper: best ≈4.44 / 3.21 / 1.65 W (coarse+fine scans).
- **Radius:** RL 44–46 and copper out to r 62 beat RL 38 / r 50; rin 24–25 for 6c, 30 for 9c.
- **Ø5 diametric assists** (final kits, scorer): BF 4.380 vs 4.136 W without (+6 %), BG 3.176 vs 3.043 W (+4 %) → kept; BH 1.843 W without vs 1.719 W with → omitted.
- **Steel matters:** air-core what-ifs of the final kits (no `--back-iron`): BF 2.152 W, BG 1.530 W, BH 1.090 W.
- **4-pole double-stack (all 16 Ø20 as 8 × 10 mm poles):** 1.84–1.87 W — beats Gen-BE but well below 8-pole: halving the pole count halves frequency, and thicker magnets only partly make it up.
- Flanges set to 0.8 mm (FDM wall rule, tall winds push on them) instead of 0.6 mm; costs ~2–3 % vs the scan rows.

## Mechanical changes vs 2026-10-03 (all three kits)

- Magnet pockets go **through** the PLA carrier so magnets sit **on** the steel (matches the scorer's image plane; 10-03 had 2.3 mm PLA between them).
- Steel discs are **3 mm** (≈0.6–0.8 T average at ~0.21–0.23 mWb/pole; 1.5 mm would run ≈1.3–1.5 T, near saturation), cut from the shipped DXF.
- Frame rods + printed standoff tubes are **outside the rotor OD** (10-03 kits put frame bolts through the spinning rotor discs) and **between coil stations** (no hole cuts a lead groove/tab).
- A printed **gap sleeve** between the rotors sets the gap and carries the magnet pull; radial M3 heat-set insert in each hub.
- M4 brace (jack) rods moved inside the coil ring (R17.5–18) so the rotors can be small; slim Ø24 hub, steel centre hole Ø26.

## Assembly warnings (tonight's kits)

- **Clap hazard is bigger than before** (steel-backed N52 across a 12.5 mm gap): brace with the 4 temporary M4 jack rods before seating the second magnet face; lower rotor B by the nuts.
- Remove temporary M4 rods and all shims before spinning.
- Brim on the 0.8 mm bobbin flanges and 1.2 mm stator webs.
- Ø5 assists (BF, BG) must be **diametrically** magnetised, glued tangentially; BH uses none.
- BH: stack the Ø20 in pairs (10 mm poles); check outer-face polarity of each stack.
- Wind bobbins before assembly; turns = SCORE.md turns-fit only (BF/BH 571 t ≈ 52–53 m per coil; BG 364 t ≈ 29 m per coil) — use a winding jig.

## Champion

**Gen-BF** at **4.380 W** — beats Gen-BE 1.684 W.

Archive: `/workspace/generators/2026-10-04-generators.tar.gz`

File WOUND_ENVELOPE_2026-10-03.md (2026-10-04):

# 2026-10-03 nightly — physics_scorer ranking

Scorer: `/workspace/generators/tools/physics_scorer/score_kit score <kit> --out <kit>` (+ `--back-iron` when steel discs are in the kit).

Baseline champion Gen-BA (corrected, `/workspace/generators/2026-10-02-fixed/gen-ba-stacked-midrotor-coppermax-mega/`): **0.615 W** matched-load @ 200 RPM.

## Ranking (PASS kits by matched-load W @ 200 RPM)

| Rank | Kit | P matched | Voc rms/ph | R Ω | Turns | Bz pk/mean | Topology | Steel? | Plate mm |
|---|---|---|---|---|---|---|---|---|---|
| 1 | **Gen-BE** `gen-be-dual-rotor-backiron-9coil-mega` | **1.684 W** | 2.41 V | 2.58 | 107 | 0.750/0.436 T | dual_rotor | yes | 409×409 |
| 2 | **Gen-BD** `gen-bd-dual-rotor-backiron-femto` | **1.174 W** | 1.86 V | 2.20 | 76 | 0.745/0.534 T | dual_rotor | yes | 409×409 |
| 3 | **Gen-BC** `gen-bc-stacked-midrotor-coppermax-giga` | **0.802 W** | 2.44 V | 5.59 | 114 | 0.337/0.187 T | mid_rotor | no | 408×409 |

## Design ideas

- **Gen-BE**: Nine-coil dual-rotor with tall bobbins (former_web 3.60 mm) and two buyable mild-steel back-iron discs; image-method steel boost.
- **Gen-BD**: Twelve-coil dual-rotor with tall bobbins and two buyable mild-steel back-iron discs; classic 8p/12c phasing plus steel.
- **Gen-BC**: Mid-rotor copper-max evolved from Gen-BA: taller former_web 3.60 mm, RL=40, bolt circle pulled to R18 so pockets stay clear.

## Assembly warnings (all kits)

- Brace M4 before seating the second magnet face (clap).
- Brim on 0.60 mm flanges / thin webs.
- Remove temporary braces and gap shims before spinning.
- Ø5 assists must be **diametrically** magnetised.
- Wind bobbins before assembly; turns = SCORE.md turns_fit only.

## Champion

**Gen-BE** at **1.684 W** (beats Gen-BA 0.615 W).

Archive: `/workspace/generators/2026-10-03-generators.tar.gz`

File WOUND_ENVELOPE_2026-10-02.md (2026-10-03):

# Night wound envelope — 2026-10-02

All three kits share the same axial wind math (26 AWG, fill 0.70, layers_per_face=2, former_web=1.20, flange_t=0.60):

| Shared | Value |
|---|---|
| wind_build_axial | **0.63 mm** |
| wind_build_radial | **0.945 mm** |
| former_bare_h | **2.40 mm** |
| coil_envelope_h | **3.66 mm** |
| run_clear | **0.50 mm** |
| gap_spacer_h | **1.13 mm** |
| m2m | **4.66 mm** |
| magnet↔wound | **0.50 mm PASS** all three |

| Kit | Turns | Coils | Copper m | Gate |
|-----|---|---|---|---|
| Gen-AZ | 220 | 12 | 328 | **PASS** |
| Gen-BA | 190 | 18 | 386 | **PASS** |
| Gen-BB | 215 | 12 | 320 | **PASS** |

Hard rule: never size air gap to bare former. See `WOUND_COIL_RULE.md`.

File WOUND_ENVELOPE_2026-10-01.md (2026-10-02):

# Night wound envelope — 2026-10-01

All three kits share the same axial wind math (26 AWG, fill 0.70, layers_per_face=2, former_web=1.20, flange_t=0.60):

| Shared | Value |
|---|---|
| wind_build_axial | **0.63 mm** |
| wind_build_radial | **0.945 mm** |
| former_bare_h | **2.40 mm** |
| coil_envelope_h | **3.66 mm** |
| run_clear | **0.50 mm** |
| gap_spacer_h | **1.13 mm** |
| m2m | **4.66 mm** |
| magnet↔wound | **0.50 mm PASS** all three |

| Kit | Turns | Coils | Copper m | Gate |
|-----|---|---|---|---|
| Gen-AW | 215 | 12 | 325 | **PASS** |
| Gen-AX | 185 | 18 | 380 | **PASS** |
| Gen-AY | 210 | 12 | 315 | **PASS** |

Hard rule: never size air gap to bare former. See `WOUND_COIL_RULE.md`.

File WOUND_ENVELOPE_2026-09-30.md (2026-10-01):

# Night wound envelope — 2026-09-30

All three kits share the same axial wind math (26 AWG, fill 0.70, layers_per_face=2, former_web=1.22, flange_t=0.60):

| Shared | Value |
|---|---|
| wind_build_axial | **0.63 mm** |
| wind_build_radial | **0.945 mm** |
| former_bare_h | **2.42 mm** |
| coil_envelope_h | **3.68 mm** |
| run_clear | **0.50 mm** |
| gap_spacer_h | **1.13 mm** |
| m2m | **4.68 mm** |
| magnet↔wound | **0.50 mm PASS** all three |

| Kit | Turns | Coils | Copper m | Gate |
|-----|---|---|---|---|
| Gen-AT | 210 | 12 | 323 | **PASS** |
| Gen-AU | 180 | 18 | 376 | **PASS** |
| Gen-AV | 205 | 12 | 312 | **PASS** |

Hard rule: never size air gap to bare former. See `WOUND_COIL_RULE.md`.

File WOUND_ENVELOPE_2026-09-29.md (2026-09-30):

# Night wound envelope — 2026-09-29

All three kits share the same axial wind math (26 AWG, fill 0.70, layers_per_face=2, former_web=1.25, flange_t=0.60):

| Shared | Value |
|---|---|
| wind_build_axial | **0.63 mm** |
| wind_build_radial | **0.945 mm** |
| former_bare_h | **2.45 mm** |
| coil_envelope_h | **3.71 mm** |
| run_clear | **0.50 mm** |
| gap_spacer_h | **1.13 mm** |
| m2m | **4.71 mm** |
| magnet↔wound | **0.50 mm PASS** all three |

| Kit | Turns | Coils | Copper m | Gate |
|-----|---|---|---|---|
| Gen-AQ | 205 | 12 | 320 | **PASS** |
| Gen-AR | 175 | 18 | 369 | **PASS** |
| Gen-AS | 200 | 12 | 307 | **PASS** |

Hard rule: never size air gap to bare former. See `WOUND_COIL_RULE.md`.

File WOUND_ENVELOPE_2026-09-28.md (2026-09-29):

# Night wound envelope — 2026-09-28

All three kits share the same axial wind math (26 AWG, fill 0.70, layers_per_face=2, former_web=1.30, flange_t=0.60):

| Shared | Value |
|---|---|
| wind_build_axial | **0.63 mm** |
| wind_build_radial | **0.945 mm** |
| former_bare_h | **2.50 mm** |
| coil_envelope_h | **3.76 mm** |
| run_clear | **0.50 mm** |
| gap_spacer_h | **1.13 mm** |
| m2m | **4.76 mm** |
| magnet↔wound | **0.50 mm PASS** all three |

| Kit | Turns | Coils | Copper m | Gate |
|-----|---|---|---|---|
| Gen-AN | 200 | 12 | 312 | **PASS** |
| Gen-AO | 165 | 18 | 353 | **PASS** |
| Gen-AP | 195 | 12 | 302 | **PASS** |

Hard rule: never size air gap to bare former. See `WOUND_COIL_RULE.md`.

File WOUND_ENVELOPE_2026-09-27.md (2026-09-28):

# Night wound envelope — 2026-09-27

All three kits share the same axial wind math (26 AWG, fill 0.70, layers_per_face=2, former_web=1.40, flange_t=0.60):

| Shared | Value |
|---|---|
| wind_build_axial | **0.63 mm** |
| wind_build_radial | **0.945 mm** |
| former_bare_h | **2.60 mm** |
| coil_envelope_h | **3.86 mm** |
| run_clear | **0.50 mm** |
| gap_spacer_h | **1.13 mm** |
| m2m | **4.86 mm** |
| magnet↔wound | **0.50 mm PASS** all three |

| Kit | Turns | Coils | Copper m | Gate |
|-----|---|---|---|---|
| Gen-AK | 190 | 12 | 301 | **PASS** |
| Gen-AL | 155 | 18 | 335 | **PASS** |
| Gen-AM | 185 | 12 | 291 | **PASS** |

Hard rule: never size air gap to bare former. See `WOUND_COIL_RULE.md`.

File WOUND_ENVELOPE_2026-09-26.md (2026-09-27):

# Wound envelope math — 2026-09-26 night

Spool assumption: **one full ~1 lb roll of 26 AWG** (insulated OD **0.45 mm**, fill **0.70**). Length budget ≈ **390 m**.

## Gen-AH (dual-rotor copper-centroid hypermicro) — #1 / NEW CHAMPION

| Var | Value |
|-----|---|
| turns / layers_per_face | 180 / 2 |
| wind_build_axial | 2×0.45×0.7 = **0.63 mm** |
| wind_build_radial | 3×0.45×0.7 = **0.945 mm** |
| former_bare_h | 1.50+2×0.60 = **2.70 mm** |
| coil_envelope_h | 2.70+2×0.63 = **3.96 mm** |
| run_clear | **0.50 mm** |
| gap_spacer_h | 0.50+0.63 = **1.13 mm** |
| m2m | 3.96+2×0.50 = **4.96 mm** |
| magnet↔wound | **0.50 mm PASS** |
| copper length | 12×180×0.136 ≈ **294 m** |
| magnets | 8+8 Ø20 @ **R=41** + 24+24 Ø5 @ {26,41,58} |

## Gen-AI (stacked dual-stator mid-rotor copper-max) — #2

| Var | Value |
|-----|---|
| turns / layers_per_face | 145 / 2 (9×2=18 coils) |
| wind_build_axial | **0.63 mm** |
| wind_build_radial | **0.945 mm** |
| former_bare_h | **2.70 mm** |
| coil_envelope_h | **3.96 mm** |
| run_clear | **0.52 mm** |
| gap_spacer_h | **1.15 mm** |
| m2m (per gap) | 3.96+2×0.52 = **5.00 mm** |
| magnet↔wound | **0.52 mm PASS** |
| copper length | 18×145×0.122 ≈ **318 m** |
| magnets | 8+8 Ø20 both faces @ R=42 + 24+24 Ø5 @ {28,42,58} |

## Gen-AJ (vernier flux-claw ultra) — #3

| Var | Value |
|-----|---|
| turns / layers_per_face | 175 / 2 |
| wind_build_axial | **0.63 mm** |
| wind_build_radial | **0.945 mm** |
| former_bare_h | **2.70 mm** |
| coil_envelope_h | **3.96 mm** |
| run_clear | **0.50 mm** |
| gap_spacer_h | **1.13 mm** |
| m2m | 3.96+2×0.50 = **4.96 mm** |
| magnet↔wound | **0.50 mm PASS** |
| copper length | 12×175×0.130 ≈ **273 m** |
| magnets | 8+8 Ø20 @ R=42 (+22.5° vernier) + 24+24 Ø5 claws @ {27,42,57} |

## Gate

All three **PASS** `WOUND_COIL_RULE.md`. No bare-former gap sizing. Spool totals all under 390 m.

### Assert (computed)
```
AH: run_clear=0.50 ≥ 0.5; m2m = 3.96 + 2×0.50 = 4.96
AI: run_clear=0.52 ≥ 0.5; m2m = 3.96 + 2×0.52 = 5.00
AJ: run_clear=0.50 ≥ 0.5; m2m = 3.96 + 2×0.50 = 4.96
```

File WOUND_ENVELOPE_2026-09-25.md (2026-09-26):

# Wound envelope math — 2026-09-25 night

Spool assumption: **one full ~1 lb roll of 26 AWG** (insulated OD **0.45 mm**, fill **0.70**). Length budget ≈ **390 m** bare-copper-equivalent mass basis.

## Gen-AE (dual-rotor hyper-micro copper-max)

| Var | Value |
|-----|---|
| turns / layers_per_face | 170 / 2 |
| wind_build_axial | 2×0.45×0.7 = **0.63 mm** |
| wind_build_radial | 3×0.45×0.7 = **0.945 mm** |
| former_bare_h | 1.50+2×0.60 = **2.70 mm** |
| coil_envelope_h | 2.70+2×0.63 = **3.96 mm** |
| run_clear | **0.52 mm** |
| gap_spacer_h | 0.52+0.63 = **1.15 mm** |
| m2m | 3.96+2×0.52 = **5.00 mm** |
| magnet↔wound | **0.52 mm PASS** |
| copper length | 12×170×0.130 ≈ **265 m** |

## Gen-AF (stacked dual-stator mid-rotor Halbach copper-max)
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

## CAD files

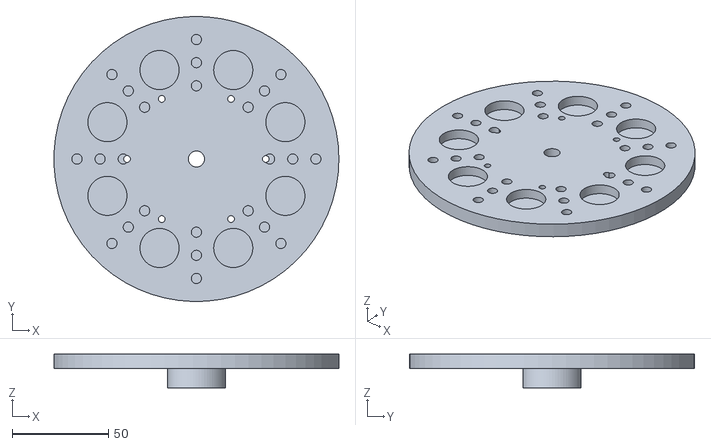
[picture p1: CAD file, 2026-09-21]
champions/2026-09-20-night-gen-p-dual-rotor-thin/print-packs/parts/rotor_face_b_x1.stl
147.9 x 148.0 x 17.5

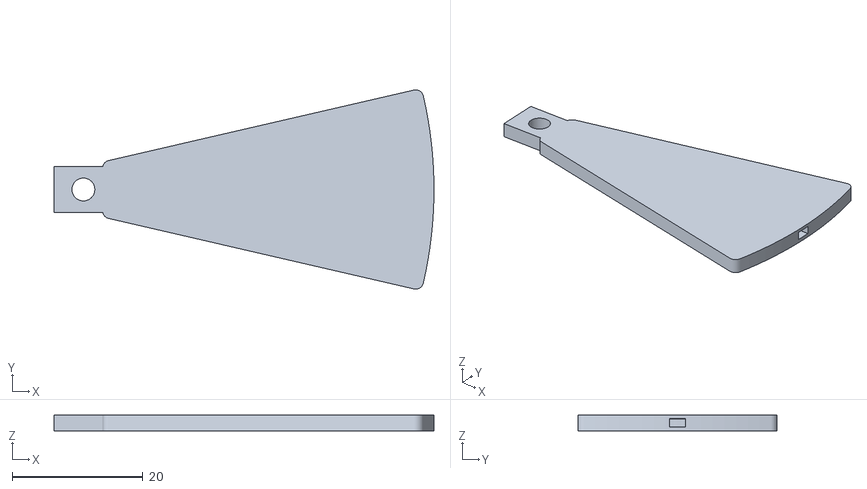
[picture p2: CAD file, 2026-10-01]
champions/2026-09-30-gen-at-dual-rotor-coppercentroid-hypermicro/coil_former.stl
58.2 x 30.5 x 2.42

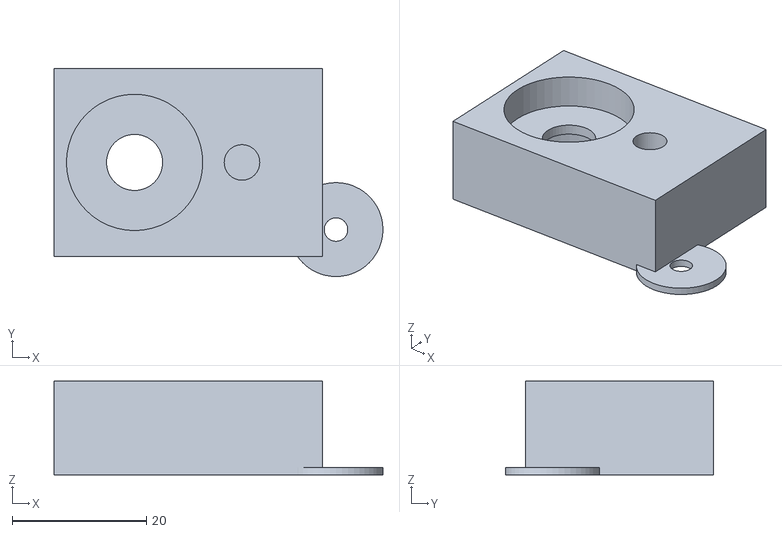
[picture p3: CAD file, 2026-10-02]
champions/2026-10-01-gen-aw-dual-rotor-coppercentroid-pico/fit_coupon.stl
49.0 x 31.0 x 14.0

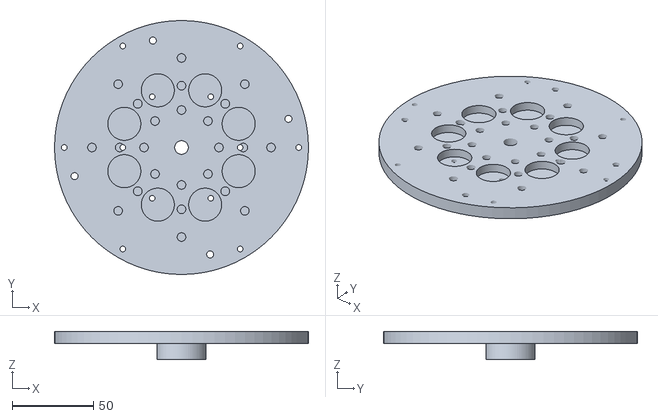
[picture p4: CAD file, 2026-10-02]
champions/2026-10-01-gen-aw-dual-rotor-coppercentroid-pico/print-packs/parts/rotor_face_b.stl
156.0 x 156.0 x 17.5

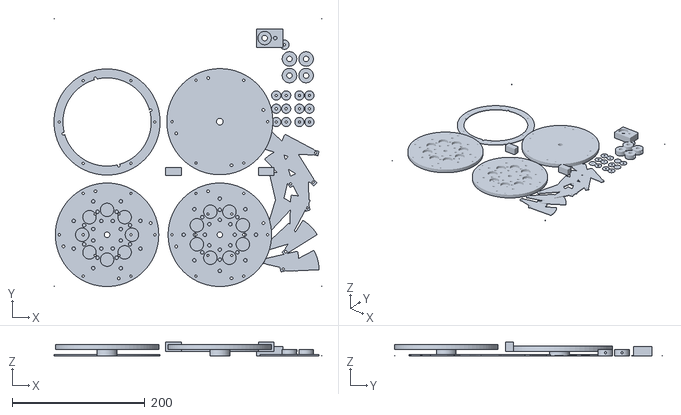
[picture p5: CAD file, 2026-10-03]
champions/2026-10-02-gen-az-dual-rotor-coppercentroid-femto/print-packs/one-plate/one_plate_layout.stl
404.0 x 404.0 x 21.2

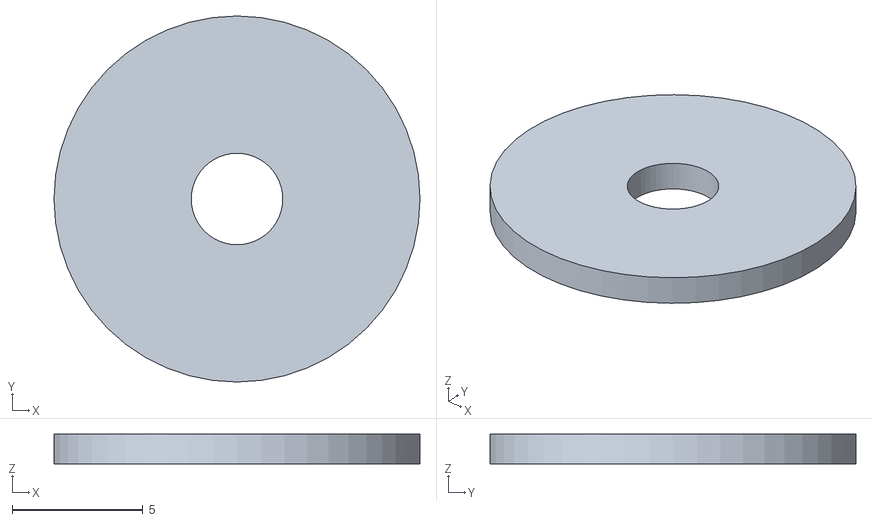
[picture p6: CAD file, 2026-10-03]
champions/2026-10-02-gen-az-dual-rotor-coppercentroid-femto/print-packs/parts/gap_spacer.stl
14.0 x 14.0 x 1.13

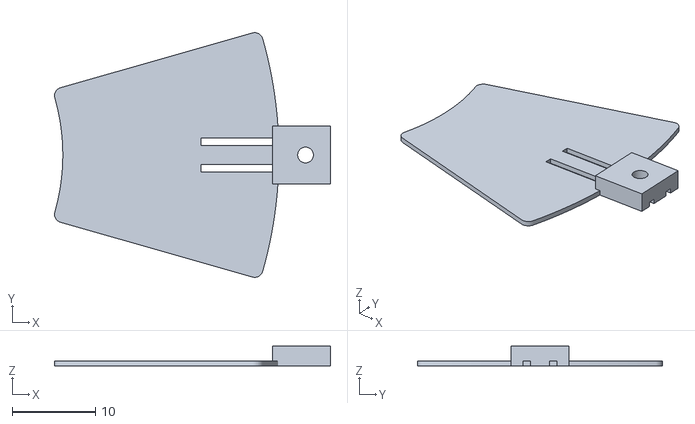
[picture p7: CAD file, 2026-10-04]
champions/2026-10-03-gen-be-dual-rotor-backiron-9coil-mega/print-packs/parts/coil_lid.stl
33.2 x 29.4 x 2.40

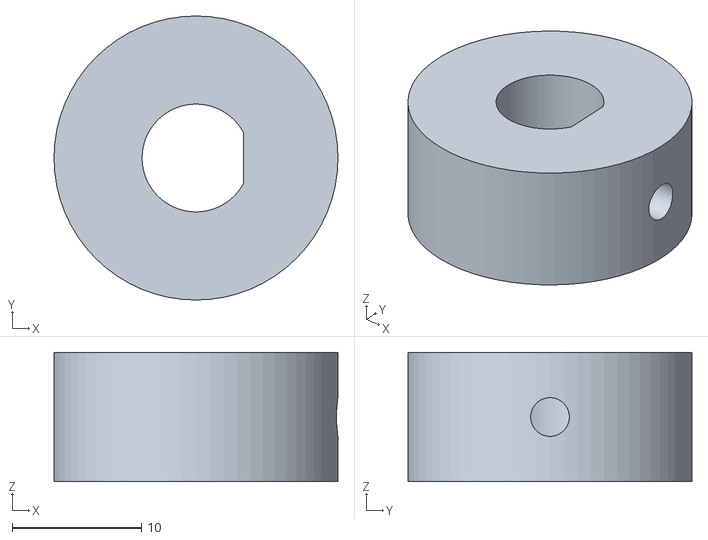
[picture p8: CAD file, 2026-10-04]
champions/2026-10-03-gen-be-dual-rotor-backiron-9coil-mega/shaft_collar.stl
22.0 x 22.0 x 10.0

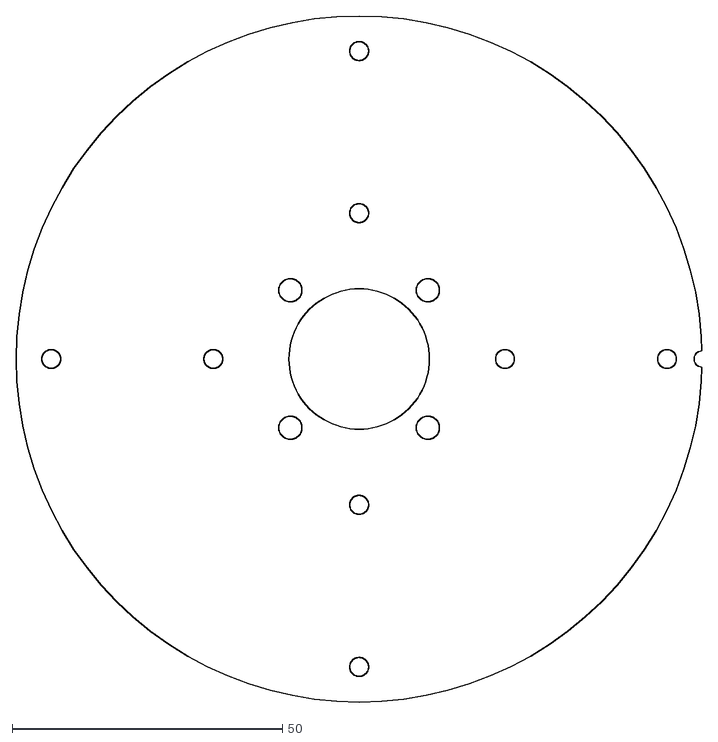
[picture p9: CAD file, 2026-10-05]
champions/2026-10-04-gen-bf-dual-rotor-steelseat-6coil-tallcopper/print-packs/laser-cut/steel_backiron_disc.dxf
127.0 x 127.0

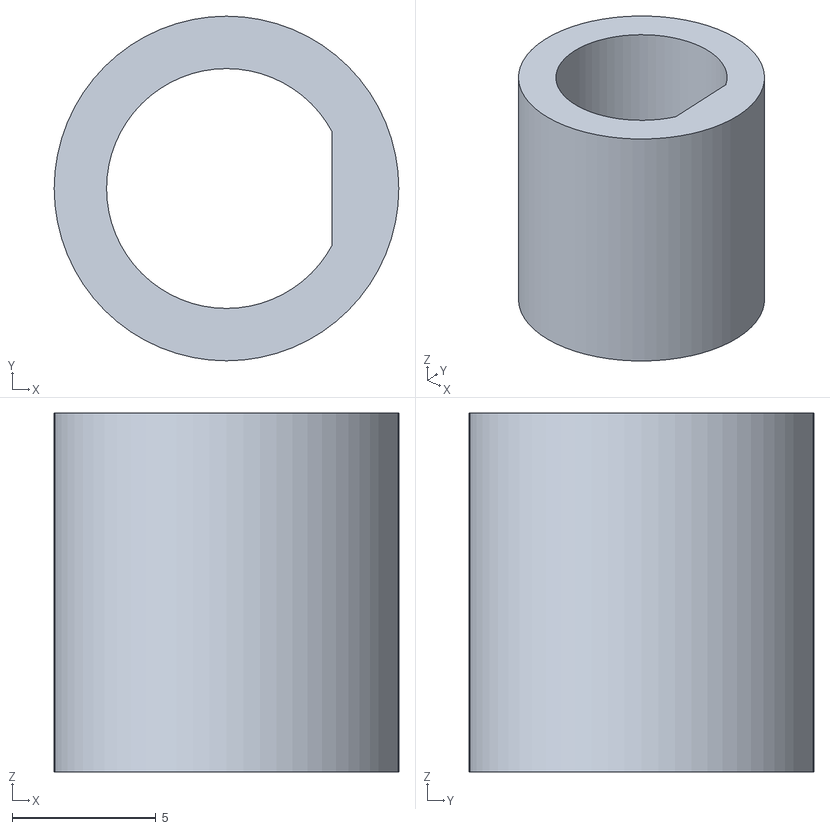
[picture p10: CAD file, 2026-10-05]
champions/2026-10-04-gen-bf-dual-rotor-steelseat-6coil-tallcopper/print-packs/parts/gap_sleeve.stl
12.0 x 12.0 x 12.5

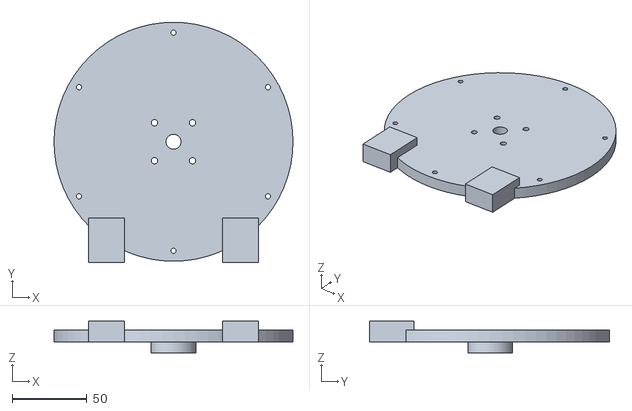
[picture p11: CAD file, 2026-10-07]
champions/2026-10-06-gen-bl-dual-rotor-steelseat-6coil-densewind/endbell_front.stl
160.0 x 161.0 x 21.2

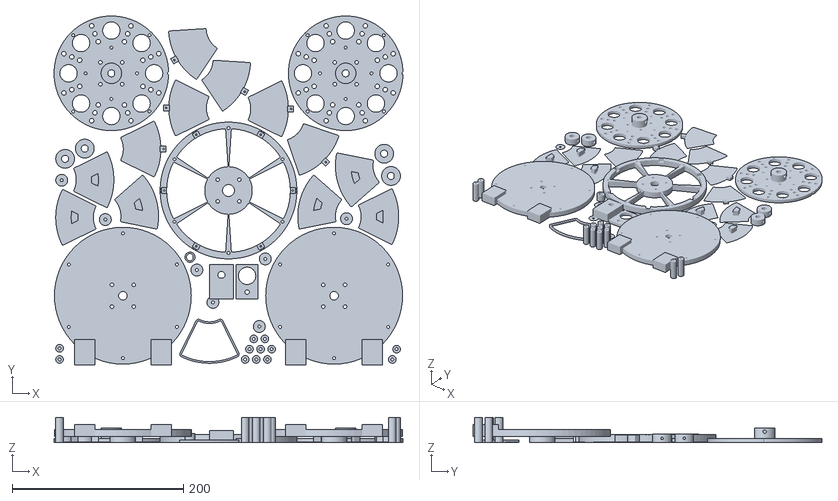
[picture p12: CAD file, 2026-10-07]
champions/2026-10-06-gen-bl-dual-rotor-steelseat-6coil-densewind/print-packs/one-plate/one_plate_layout.stl
407.9 x 408.0 x 29.6

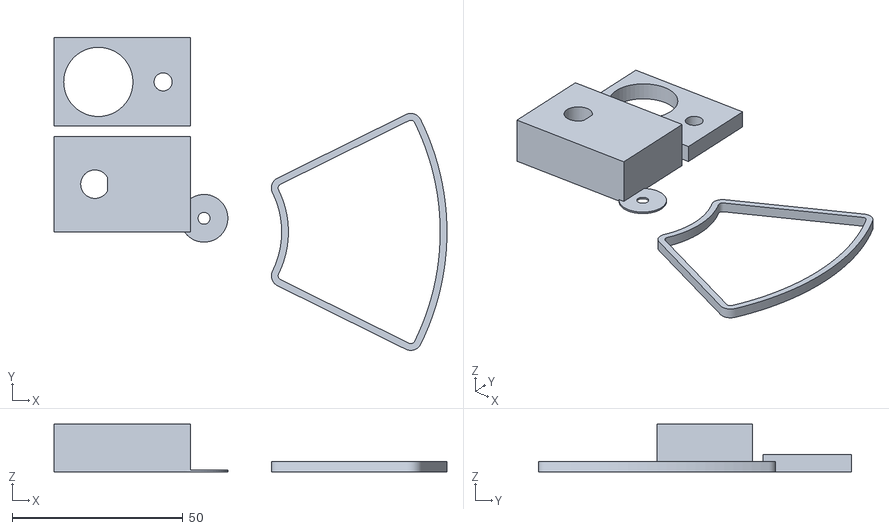
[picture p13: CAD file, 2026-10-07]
champions/2026-10-06-gen-bl-dual-rotor-steelseat-6coil-densewind/print-packs/parts/fit_coupon.stl
115.2 x 91.8 x 14.0

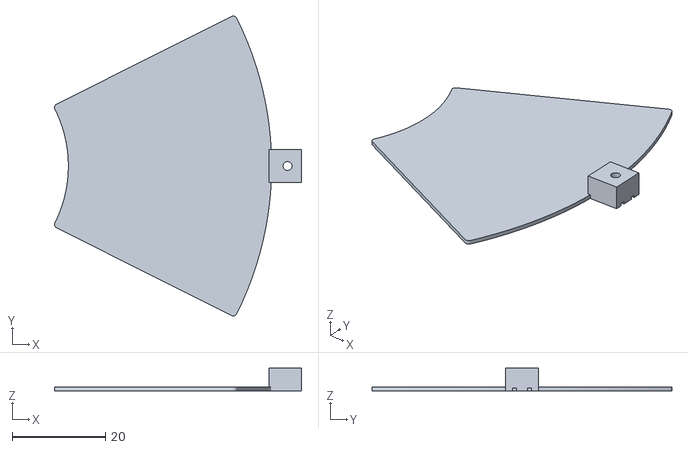
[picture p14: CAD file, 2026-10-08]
champions/2026-10-07-gen-bo-dual-rotor-flushseat-6coil-widelip/gen-bo-dual-rotor-flushseat-6coil-widelip/print-packs/parts/coil_lid.stl
53.0 x 64.3 x 4.85

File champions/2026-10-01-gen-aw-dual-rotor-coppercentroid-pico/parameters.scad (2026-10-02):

// =============================================================================
// Gen-AW Dual-rotor copper-centroid pico AFPM - WOUND-AWARE (HARD GATE)
// PRIMARY challenger vs Gen-AT. Magnets @ R=38.0 + 215 t + former_web 1.20 -> m2m 4.66.
// =============================================================================

// --- Wire / wind budget (26 AWG, ~1 lb spool ~ 390 m bare-equiv) --------------
wire_awg            = 26;
wire_od             = 0.45;     // insulated OD mm
turns               = 215;      // +5 vs Gen-AT 210
fill                = 0.70;
layers_per_face     = 2;        // axial layers proud of EACH flange
wind_build_axial    = layers_per_face * wire_od * fill;   // 0.63 mm
wind_build_radial   = 3 * wire_od * fill;                 // 0.945 mm

// --- Pancake former (bare STL) -----------------------------------------------
coil_id_r           = 14.0;     // copper-centroid window centered ~R=38.0
coil_od_r           = 62.0;
span_deg            = 26.0;     // 12 stations x 30 deg pitch
former_web          = 1.20;     // print floor for LB walls (was AT 1.22)
flange_t            = 0.60;
wall                = 1.2;
slot_w              = 2.4;
mount_hole          = 3.5;
tab_len             = 7.0;

former_bare_h       = former_web + 2 * flange_t;            // 2.40 mm
coil_envelope_h     = former_bare_h + 2 * wind_build_axial; // 3.66 mm

// --- Running clearance (magnet face -> WOUND face) EACH side ------------------
run_clear           = 0.50;     // PASS floor >= 0.5
gap_spacer_h        = run_clear + wind_build_axial;         // 1.13 mm
m2m                 = coil_envelope_h + 2 * run_clear;      // 4.66 mm (beats Gen-AT 4.68)

// --- Mid stator (12 pancakes 3ph; winds proud both faces) ---------------------
coil_stations       = 12;
bay_r_in            = coil_id_r - 2.0 - wind_build_radial;
bay_r_out           = coil_od_r + 2.0 + wind_build_radial;
bay_span            = span_deg + 4.0;
bay_offset          = 2.0;
stator_thick        = former_bare_h;                        // winds proud +/-Z
stator_od           = 160.0;
shaft_clear_stator  = 34.0;
coil_mount_r        = 25.0;

// --- Rotors (x2) - 8xO20 @ R=38.0 (copper centroid) + 24xO5 Halbach ----------
large_pocket_d      = 20.3;
small_pocket_d      = 5.3;
pocket_h            = 5.2;
large_n             = 8;
R_large             = 38.0;     // covers ~28-48 over copper centroid ~38.0
R_small_inner       = 23.0;
R_small_mid         = 38.0;
R_small_outer       = 55.0;
carrier_od          = 156.0;
carrier_thick       = 7.5;
hub_h               = 10.0;
hub_od              = 30.0;
rotor_b_offset_deg  = 22.5;

// --- Modular MAX interface (Gen-E family) ------------------------------------
shaft_bore          = 8.35;
bearing_d           = 21.85;
bearing_h           = 7.2;
m3_clear            = 3.5;
bolt_r_inner        = 36.0;
bolt_n_inner        = 6;
flange_bolt_r       = 72.0;
flange_bolt_n       = 6;
brace_r             = 68.0;
brace_d             = 4.3;
brace_n             = 4;

spacer_pad_od       = 14.0;
spacer_pad_id       = m3_clear;
endbell_od          = 160.0;
endbell_thick       = 8.0;
endbell_shaft_clear = 10.0;

$fn = 64;

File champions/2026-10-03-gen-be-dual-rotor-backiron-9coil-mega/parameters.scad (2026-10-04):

// =============================================================================
// Gen-BE — nightly 2026-10-03 (physics_scorer, honest magpylib watts)
// Clocking 0 deg (magnets N facing S) + D-flat keyed bore + index notch + flip-symmetric braces/bolts.
// Windable 2-piece bobbin; turns = physics_scorer turns_fit; copper only between flanges.
// former_web = 3.60 mm (taller copper vs Gen-BA 2.46) — gap grows with web (honest Bz tradeoff).
// Steel back-iron: two buyable mild-steel discs behind each rotor (score with --back-iron).
// =============================================================================
topology            = "dual_rotor";

// --- Wire / winding (physics_scorer winding-fit) -------------------------------
wire_awg            = 26;
wire_od             = 0.45;     // insulated OD mm (bare 0.405)
fill_realistic      = 0.60;     // insulated-wire area / window, hand-wound layered
turns               = 107;       // = physics_scorer turns_fit (do NOT raise)
coil_former_type    = "bobbin";
coil_core_inset     = 7.90;     // radial copper build: hub = copper boundary inset by this
wind_build_axial    = 0.0;      // nothing proud of the flanges
wind_build_radial   = 0.0;

// --- Bobbin (base + lid) ---------------------------------------------------------
coil_id_r           = 26.00;    // copper boundary sector (over the magnet track)
coil_od_r           = 50.00;
span_deg            = 31.84;    // = pitch - 2*asin((wall+0.85)/coil_id_r) -> >=1.2 mm stator web
former_web          = 3.60;     // copper height between flanges
flange_t            = 0.60;
wall                = 1.00;     // flange lip beyond copper
former_bare_h       = former_web + 2 * flange_t;
coil_envelope_h     = former_bare_h + 2 * wind_build_axial;
tab_w               = 7.0;
tab_len             = 7.0;
tab_h               = former_bare_h / 2;
pin_d               = 1.9;      // 1.75 mm filament locating pin
coil_mount_r        = coil_od_r + 0.2 + 4.0;
lead_y              = 1.6;
lead_slot_w         = 0.9;
lead_groove_d       = 0.6;

// --- Gap -------------------------------------------------------------------------
run_clear           = 0.50;     // rotor face -> flange
gap_spacer_h        = run_clear + wind_build_axial;
m2m                 = coil_envelope_h + 2 * run_clear;

// --- Stator ----------------------------------------------------------------------
coil_stations       = 9;
bay_clear           = 0.25;
stator_thick        = former_bare_h;                        // bobbins flush both faces
stator_od           = 158.0;
shaft_clear_stator  = 14.0;     // stator is static; shaft only

// --- Rotor(s) --------------------------------------------------------------------
magnet_Br           = 1.43;     // N52
halbach_magnetisation = "diametric"; // O5x5 assist magnets MUST be DIAMETRICALLY magnetised (tangential)
rotor_b_same_axis   = true;     // same-index magnets share one axis: N faces S across the gap
large_pocket_d      = 20.3;
small_pocket_d      = 5.3;
pocket_h            = 5.2;
large_n             = 8;
R_large             = 38.0;
R_small_inner       = 24.0;
R_small_mid         = 38.0;
R_small_outer       = 55.0;
carrier_od          = 156.0;
carrier_thick       = 7.5;
hub_h               = 10.0;
hub_od              = 30.0;
rotor_b_offset_deg  = 0.0;      // CLOCKING: magnets directly opposite
shaft_key           = "dflat";
dflat_depth         = 0.5;      // 8 mm shaft with 0.5 mm flat (7.5 across flat)
index_notch_d       = 3.0;

// --- Modular MAX interface (Gen-E family) -----------------------------------------
shaft_bore          = 8.35;
dflat_x             = 4.0 - dflat_depth + (shaft_bore - 8.0) / 2;
bearing_d           = 21.85;
bearing_h           = 7.2;
m3_clear            = 3.5;
bolt_r_inner        = 30.0;
bolt_n_inner        = 4;
bolt_inner_angles   = [22.5, -22.5, 157.5, 202.5];  // between poles, flip-symmetric
flange_bolt_r       = 72.0;
flange_bolt_n       = 6;
brace_r             = 68.0;
brace_d             = 4.3;
brace_n             = 4;
brace_angles        = [45, 135, 225, 315];          // flip-symmetric

spacer_pad_od       = 14.0;
spacer_pad_id       = m3_clear;
endbell_od          = 158.0;
endbell_thick       = 8.0;
endbell_shaft_clear = 10.0;
plate_max_mm        = 410;

$fn = 64;

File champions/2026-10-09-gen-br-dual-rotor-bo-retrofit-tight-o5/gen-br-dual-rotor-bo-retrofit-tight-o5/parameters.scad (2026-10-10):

// =============================================================================
// Gen-BR — nightly 2026-10-09 (physics_scorer, honest magpylib watts)
// Rotor-only swap for Gen-BO: the diametric Ø5 assists move from ±7 mm to ±6.2 mm around the R50 pole ring (R43.8/50/56.2), the closest spacing that still leaves a 0.9 mm printed web between Ø5.3 pockets (rule ≥0.8). Everything else — bobbins, 595 t windings, stator, Ø134 steel — is Gen-BO. Tonight's 138-row refine scan (ring radius 49–51, coil radii ±0.5, build ±0.4, copper height 7.9–8.3) found nothing better: the 8p/6c flush-seat family is saturated under the ~370 m wire budget, so this is a hair-width step (about +0.2 % over Gen-BO), not a breakthrough.
// Clocking 0 deg (magnets N facing S) + D-flat keyed bore + index notch + flip-symmetric hole map.
// Windable 2-piece bobbin; turns = physics_scorer turns_fit; copper only between flanges.
// Steel back-iron: 2× Ø134 × 4.76 mm (3/16") mild-steel discs (steel_backiron_disc.dxf); magnets sit ON the steel
// (through-pockets) -> score with --back-iron.
// =============================================================================
topology            = "dual_rotor";

// --- Wire / winding (physics_scorer winding-fit) -------------------------------
wire_awg            = 26;
wire_od             = 0.45;     // insulated OD mm (bare 0.405)
fill_realistic      = 0.65;     // insulated-wire area / window (DENSE layered wind with a jig; scorer cap 0.65)
turns               = 595;       // = physics_scorer turns_fit (do NOT raise)
coil_former_type    = "bobbin";
coil_core_inset     = 18.00;     // radial copper build: hub = copper boundary inset by this
wind_build_axial    = 0.0;      // nothing proud of the flanges
wind_build_radial   = 0.0;

// --- Bobbin (base + lid) ---------------------------------------------------------
coil_id_r           = 28.00;    // copper boundary sector
coil_od_r           = 70.00;
span_deg            = 53.24;    // = pitch - 2*asin((wall+0.85)/coil_id_r) -> >=1.2 mm stator web
former_web          = 8.10;     // copper height between flanges (TALL copper: steel keeps Bz up)
flange_t            = 0.80;     // >= 0.8 mm FDM wall rule (tall winds push on the flanges)
wall                = 0.80;     // flange lip beyond copper
former_bare_h       = former_web + 2 * flange_t;
coil_envelope_h     = former_bare_h + 2 * wind_build_axial;
tab_w               = 7.0;
tab_len             = 7.0;
tab_h               = former_bare_h / 2;
pin_d               = 1.9;      // 1.75 mm filament locating pin
coil_mount_r        = coil_od_r + 0.2 + 4.0;
lead_y              = 1.6;
lead_slot_w         = 0.9;
lead_groove_d       = 0.6;

// --- Gap -------------------------------------------------------------------------
run_clear           = 0.50;     // rotor face -> flange
gap_spacer_h        = run_clear + wind_build_axial;
m2m                 = coil_envelope_h + 2 * run_clear;   // rotor face to rotor face (= gap_sleeve length)

// --- Stator ----------------------------------------------------------------------
coil_stations       = 6;
bay_clear           = 0.25;
stator_thick        = former_bare_h;                        // bobbins flush both faces
stator_od           = 158;
shaft_clear_stator  = 14.0;     // stator is static; gap sleeve OD 12 spins inside

// --- Rotor(s) --------------------------------------------------------------------
magnet_Br           = 1.43;     // N52
magnet_d_large      = 20.0;
magnet_h_large      = 5.0;      // one O20x5 per pocket
magnet_h_small      = 5.0;      // one O5x5 per pocket
halbach_magnetisation = "diametric"; // O5x5 assist magnets MUST be DIAMETRICALLY magnetised (tangential)
rotor_b_same_axis   = true;     // same-index magnets share one axis: N faces S across the gap
large_pocket_d      = 20.3;
small_pocket_d      = 5.3;
pocket_h            = 5.00;     // THROUGH the carrier: magnet back face sits on the steel disc (FLUSH seat: carrier = magnet height, magnet face level with the rotor face)
large_n             = 8;
R_large             = 50.0;
R_small_inner       = 43.8;
R_small_mid         = 50.0;
R_small_outer       = 56.2;
small_r_list        = [R_small_inner, R_small_mid, R_small_outer];   // O5 pockets between poles
carrier_od          = 134.0;
carrier_thick       = pocket_h;
hub_h               = 12.0;     // > steel_t + insert: radial set-screw clears the steel
hub_od              = 24.0;     // slim hub so the M4 brace rods fit at R~18 inside the coil ring
hub_insert_d        = 4.0;      // M3 heat-set insert, radial, bears on the D-flat
rotor_b_offset_deg  = 0.0;      // CLOCKING: magnets directly opposite
shaft_key           = "dflat";
dflat_depth         = 0.5;      // 8 mm shaft with 0.5 mm flat (7.5 across flat)
index_notch_d       = 3.0;

// --- Steel back-iron (buyable laser-cut) -------------------------------------------
steel_t             = 4.76;      // mild steel thickness (image method ignores it; sized from steel_flux.py so the return path stays well below saturation)
steel_center_hole   = 26.0;     // slips over the rotor hub (OD 24)
steel_od            = carrier_od;   // steel disc OD = rotor carrier OD

// --- Modular MAX interface ----------------------------------------------------------
shaft_bore          = 8.35;
dflat_x             = 4.0 - dflat_depth + (shaft_bore - 8.0) / 2;
bearing_d           = 21.85;
bearing_h           = 7.2;
m3_clear            = 3.5;
bolt_r_inner        = 30.0;     // M3 steel-disc clamp bolts (inside the magnet ring)
bolt_n_inner        = 4;
bolt_inner_angles   = [0, 90, 180, 270];
bolt_r_outer        = 63.0;     // M3 steel-disc clamp bolts (outside the magnet ring)
bolt_outer_angles   = [45, 135, 225, 315];
flange_bolt_r       = 73.0;     // frame rods: OUTSIDE the rotor OD (rotors spin inside them)
flange_bolt_n       = 6;
flange_bolt_offset  = 30.00;    // between coil stations -> never cuts a lead groove/tab
brace_r             = 18.0;
brace_d             = 4.3;      // temporary M4 jack rods (assembly only)
brace_n             = 4;
brace_angles        = [45, 135, 225, 315];          // flip-symmetric

spacer_pad_od       = 14.0;
spacer_pad_id       = m3_clear;
endbell_od          = 158;
endbell_thick       = 8.0;
endbell_shaft_clear = 10.0;
collar_h            = 10.0;
standoff_od         = 9.0;
frame_standoff_h    = run_clear + carrier_thick + hub_h + collar_h + 2.0;
sleeve_od           = 12.0;
plate_max_mm        = 410;

$fn = 64;

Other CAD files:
champions/2026-10-02-gen-az-dual-rotor-coppercentroid-femto/rotor_face_b.stl
champions/2026-10-09-gen-br-dual-rotor-bo-retrofit-tight-o5/gen-br-dual-rotor-bo-retrofit-tight-o5/print-packs/laser-cut/steel_backiron_disc.dxf
champions/2026-10-09-gen-br-dual-rotor-bo-retrofit-tight-o5/gen-br-dual-rotor-bo-retrofit-tight-o5/print-packs/one-plate/one_plate_layout.stl
champions/2026-10-09-gen-br-dual-rotor-bo-retrofit-tight-o5/gen-br-dual-rotor-bo-retrofit-tight-o5/print-packs/parts/gap_spacer.stl
champions/2026-10-02-gen-az-dual-rotor-coppercentroid-femto/parameters.scad
champions/2026-09-20-gen-m-wound/coil_former.scad
champions/2026-09-20-gen-m-wound/coil_former.stl
champions/2026-09-20-gen-m-wound/endbell_front.scad
champions/2026-09-20-gen-m-wound/endbell_front.stl
champions/2026-09-20-gen-m-wound/endbell_rear.scad
champions/2026-09-20-gen-m-wound/endbell_rear.stl
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

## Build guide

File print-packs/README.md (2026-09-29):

# Print packs (one-plate + parts)

**Current MAX tip:** [`gen-an-dual-rotor-coppercentroid-hyper/`](gen-an-dual-rotor-coppercentroid-hyper/) — one-plate **404×404 mm** for Anycubic Kobra 3 Max (≤408 usable).

Same-night runners:
- [`gen-ao-stacked-midrotor-coppermax-ultra/`](gen-ao-stacked-midrotor-coppermax-ultra/) — 405.5×404
- [`gen-ap-vernier-fluxclaw-mega/`](gen-ap-vernier-fluxclaw-mega/) — 404×404

Prior tip pack: [`gen-ak-dual-rotor-coppercentroid-ultra/`](gen-ak-dual-rotor-coppercentroid-ultra/).

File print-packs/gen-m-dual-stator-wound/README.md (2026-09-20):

# Gen-M — Dual-stator sandwich AFPM / wound-aware 9+9 coil 3φ

**FIRST wound-compliant MAX champion** (2026-09-20 ET). Evolution of withdrawn Gen-J: same dual-face rotor + two stator packs, but stack and bays sized for the **wound copper envelope**, not bare former STLs.

**Wound gate: PASS** — see [WOUND_ENVELOPE.md](../WOUND_ENVELOPE.md) and table below.

## Wound envelope (mandatory)

| Param | Value | Notes |
|---|---|---|
| Wire | **26 AWG** | insulated OD **0.45 mm** |
| Turns | **120** / pancake | ~1 lb spool covers 18×120 |
| fill | **0.70** | packing factor |
| layers_per_face | **3** | axial layers budgeted proud of each flange |
| `wind_build_axial` | **0.945 mm** | `3 × 0.45 × 0.7` each face |
| `former_web` | **3.2 mm** | |
| `flange_t` | **1.0 mm** | |
| `former_bare_h` | **5.2 mm** | web + 2×flange |
| `coil_envelope_h` | **7.09 mm** | bare + 2×wind_build_axial |
| `run_clear` | **0.85 mm** | magnet face → **wound** face (≥0.8) |
| `gap_spacer_h` | **1.795 mm** | `run_clear + wind_build_axial` |
| `bay_depth` | **6.145 mm** | bare + back-face wind (front wind proud) |
| magnet→wound | **0.85 mm** | `gap_spacer_h − wind_build_axial` **PASS** |

Stator bays use expanded radial outline (`bay_r_in/out`, `bay_offset`) for wound radial width, not bare former.

Explicit params live in `parameters.scad` (included by all parts).

## Magnet inventory (full kit)

| Kit | Qty | Placement |
|-----|-----|---|
| Ø20×5 | **8** | +Z face @ R=52 mm, 45° steps |
| Ø20×5 | **8** | −Z face @ R=52 mm, offset **+22.5°** |
| Ø5×5 | **24** | +Z Halbach triplets @ R={40,52,64} |
| Ø5×5 | **24** | −Z Halbach triplets (+22.5°) |

Pockets: **Ø20.3×5.2**, **Ø5.3×5.2**. Carrier OD **148 mm**, thick **12 mm**. Hub Ø30×10.

### Polarity map

**+Z face:** alternate N-S (even indices N toward +Z stator).  
**−Z face:** alternate N-S with N toward −Z stator on even indices.  
**Halbach smalls:** mid circumferential, edge smalls reinforce pole tips.  
**Assembly:** Glue one face completely, dry-fit both wound stator packs with `gap_spacer` pads, brace, then glue second face. **Wind all 18 formers before assembly.**

## Coils

- **9 + 9 = 18** pancakes (3φ × 3 per stator) — 12+12 preferred for copper but one-plate on ~410×410 keeps **9+9** (wider 34° formers)
- **26 AWG × 120 t** each; star 3φ per stator; series/parallel packs for V/I trade
- Mean turn ~0.11 m → 18×120×0.11 ≈ **240 m** copper (~fits 1 lb 26 AWG spool)

## Stack (one side)

```
magnet face
  └── run_clear 0.85 mm
wound copper face (front wind_build_axial proud of stator)
  └── coil_envelope through bay
stator back web
```

`gap_spacer` on flange bolts sets magnet → stator face = 1.795 mm so magnet→wound = 0.85 mm after the stated wind.

## Estimated EMF / power

B_gap Halbach-boosted ≈ **0.50–0.70 T** per face. Dual surfaces + full 18-coil wind.

| RPM | Est. combined RMS (26 AWG 120 t) | Est. matched power |
|-----|---|---|
| 200 | **~8–16 V** (series packs) | **~5–12 W** |
| 300 | **~12–24 V** | **~9–20 W** |
| 1000 | **~40–80 V** | **~25–55 W** (thermal) |

## Modular interface

| Spec | Value |
|---|---|
| Shaft | Ø8 / bore Ø8.35 |
| Bearings | 608ZZ seats Ø21.85×7.2 |
| Hub | Ø30×10 |
| Endbell / stator bolts | **6× M3 @ R=72** (Gen-E family) |
| Brace | **4× M4 @ R≈68** |
| M3 clear | Ø3.4–3.5 |

## Parts to print

| File | Qty | Notes |
|---|-----|---|
| `rotor_sandwich.stl` | 1 | Magnet faces; brim |
| `stator_core.stl` | **2** | Wound-sized bays up |
| `coil_former.stl` | **18** | Flange on bed; **wind before assembly** |
| `gap_spacer.stl` | **12** | h=`gap_spacer_h` (wound math) |
| `endbell_front/rear.stl` | 1 each | |
| `shaft_collar.stl` | 2–4 | |
| `fit_coupon.stl` | 1 | Dual pockets + 608 + spacer height |

One-plate: `print-packs/one-plate/` (fits Kobra 3 Max usable ~410×410).

## BOM

- 16× Ø20×5 + 48× Ø5×5 N52
- Ø8 shaft, 2–4× 608ZZ, M3 + heat-set inserts, 4× M4 brace rod
- **26 AWG** magnet wire (~1 lb)
- Optional thin steel backing rings behind each magnet face

## Print / safety

**0.4 mm** nozzle default. PETG/ABS preferred. Walls ≥0.8 (load 1.2). Brace both stators before seating the second magnet face. Keep Halbach smalls jigged.

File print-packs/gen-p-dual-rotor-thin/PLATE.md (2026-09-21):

# One-plate pack — Gen-P Dual-rotor thin-gap AFPM / 12-coil wound

**Printer:** Anycubic Kobra 3 Max Combo (420×420 mm bed, usable **410×410** with margin)
**Gap between parts:** ~**5 mm** (circle-aware nesting for disk parts)
**Packed span:** **410.0 × 410.0 mm**
**Fits one plate:** **YES**

## Quantity list

| Part | Qty | Approx XY (mm) | Shape |
|---|-----|---|---|
| `rotor_face_a` | 1 | 147.9 × 148.0 | disk |
| `rotor_face_b` | 1 | 147.9 × 148.0 | disk |
| `stator_core` | 1 | 151.9 × 152.0 | disk |
| `coil_former` | 12 | 38.2 × 26.7 | rect |
| `gap_spacer` | 12 | 14.0 × 14.0 | rect |
| `endbell_front` | 1 | 156.0 × 153.0 | disk |
| `endbell_rear` | 1 | 156.0 × 153.0 | disk |
| `shaft_collar` | 2 | 22.0 × 22.0 | rect |
| `fit_coupon` | 1 | 55.0 × 28.0 | rect |

## Files

- `one_plate_layout.stl` — all instances arranged flat on Z=0
- `preview.png` — labeled top-down orthographic view
- Individual STLs in `../parts/` (filename includes `_xN` qty)

## Print notes

WOUND PASS. DUAL-ROTOR CLAP — M4 braces before second magnet face. Wind 12 formers before assembly. gap_spacer_h=1.43 from wound math (m2m=7.26).

- Orient as designed in source READMEs (magnet pockets open upward where applicable).
- Slice the combined plate as one job, or print individual parts from `parts/`.
- Brim recommended for large rotors/carriers.
- Disk parts nested circle-aware (AABB corners may visually overlap; solid geometry does not collide).

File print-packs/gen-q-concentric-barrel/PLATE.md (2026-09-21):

# One-plate pack — Gen-Q Concentric dual-gap Halbach barrel / 12-bobbin wound

**Printer:** Anycubic Kobra 3 Max Combo (420×420 mm bed, usable **410×410** with margin)
**Gap between parts:** ~**5 mm** (circle-aware nesting for disk parts)
**Packed span:** **410.0 × 410.0 mm**
**Fits one plate:** **YES**

## Quantity list

| Part | Qty | Approx XY (mm) | Shape |
|---|-----|---|---|
| `rotor_outer_drum` | 1 | 127.9 × 128.0 | disk |
| `rotor_inner_hub` | 1 | 30.0 × 30.0 | disk |
| `stator_annulus` | 1 | 95.9 × 96.0 | disk |
| `coil_former` | 12 | 12.4 × 16.4 | rect |
| `endbell_front` | 1 | 134.0 × 131.0 | disk |
| `endbell_rear` | 1 | 134.0 × 131.0 | disk |
| `shaft_collar` | 2 | 22.0 × 22.0 | rect |
| `fit_coupon` | 1 | 44.0 × 30.0 | rect |

## Files

- `one_plate_layout.stl` — all instances arranged flat on Z=0
- `preview.png` — labeled top-down orthographic view
- Individual STLs in `../parts/` (filename includes `_xN` qty)

## Print notes

WOUND PASS. Slots sized for wound tip/side. magnet↔wound tip≈1.05 mm. Hub-down drums; flange on bed for bobbins.

- Orient as designed in source READMEs (magnet pockets open upward where applicable).
- Slice the combined plate as one job, or print individual parts from `parts/`.
- Brim recommended for large rotors/carriers.
- Disk parts nested circle-aware (AABB corners may visually overlap; solid geometry does not collide).

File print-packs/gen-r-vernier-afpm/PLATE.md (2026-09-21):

# One-plate pack — Gen-R Vernier AFPM 18-coil / 8+8 wound

**Printer:** Anycubic Kobra 3 Max Combo (420×420 mm bed, usable **410×410** with margin)
**Gap between parts:** ~**5 mm** (circle-aware nesting for disk parts)
**Packed span:** **410.0 × 410.0 mm**
**Fits one plate:** **YES**

## Quantity list

| Part | Qty | Approx XY (mm) | Shape |
|---|-----|---|---|
| `rotor_vernier_a` | 1 | 149.9 × 150.0 | disk |
| `rotor_vernier_b` | 1 | 149.9 × 150.0 | disk |
| `stator_core` | 1 | 155.9 × 156.0 | disk |
| `coil_former` | 18 | 37.2 × 17.9 | rect |
| `gap_spacer` | 12 | 14.0 × 14.0 | rect |
| `endbell_front` | 1 | 160.0 × 157.0 | disk |
| `endbell_rear` | 1 | 160.0 × 157.0 | disk |
| `shaft_collar` | 2 | 22.0 × 22.0 | rect |
| `fit_coupon` | 1 | 55.0 × 28.0 | rect |

## Files

- `one_plate_layout.stl` — all instances arranged flat on Z=0
- `preview.png` — labeled top-down orthographic view
- Individual STLs in `../parts/` (filename includes `_xN` qty)

## Print notes

WOUND PASS. Vernier +11.25°. DUAL-ROTOR CLAP. steel_return_register OPTIONAL — print ×0–2 separately (not on one-plate). Wind 18 formers. m2m=7.16.

- Orient as designed in source READMEs (magnet pockets open upward where applicable).
- Slice the combined plate as one job, or print individual parts from `parts/`.
- Brim recommended for large rotors/carriers.
- Disk parts nested circle-aware (AABB corners may visually overlap; solid geometry does not collide).

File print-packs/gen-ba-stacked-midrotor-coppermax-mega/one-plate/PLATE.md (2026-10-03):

# gen-ba-stacked-midrotor-coppermax-mega one-plate — Kobra 3 Max (≤408.0×408.0 usable)

- **Measured trimesh bbox: 405.50 × 404.00 mm** (PASS ≤408.0)
- Layout: `one_plate_layout.stl` (authoritative) + `one_plate_layout.scad` (doc)
- Preview: `preview.png`

## Includes
- Mid rotor, 1 stator (print ×2), 1 endbell (print ×2), 9 formers (dup to 18), 9 spacers, 2 collars, coupon

## Print notes
- Brim on thin former flanges (0.60 mm)
- Wind all formers **before** assembly
- MID-ROTOR CLAP: brace before seating either stator

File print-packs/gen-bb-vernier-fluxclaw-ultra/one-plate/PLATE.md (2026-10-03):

# gen-bb-vernier-fluxclaw-ultra one-plate — Kobra 3 Max (≤408.0×408.0 usable)

- **Measured trimesh bbox: 404.00 × 404.00 mm** (PASS ≤408.0)
- Layout: `one_plate_layout.stl` (authoritative) + `one_plate_layout.scad` (doc)
- Preview: `preview.png`

## Includes
- Dual-rotor vernier: Rotor A/B, stator, endbell, 12 formers, 12 spacers, 4 collars, coupon

## Print notes
- Brim on thin former flanges (0.60 mm)
- Wind all formers **before** assembly
- DUAL-ROTOR CLAP: install M4 braces before seating second rotor

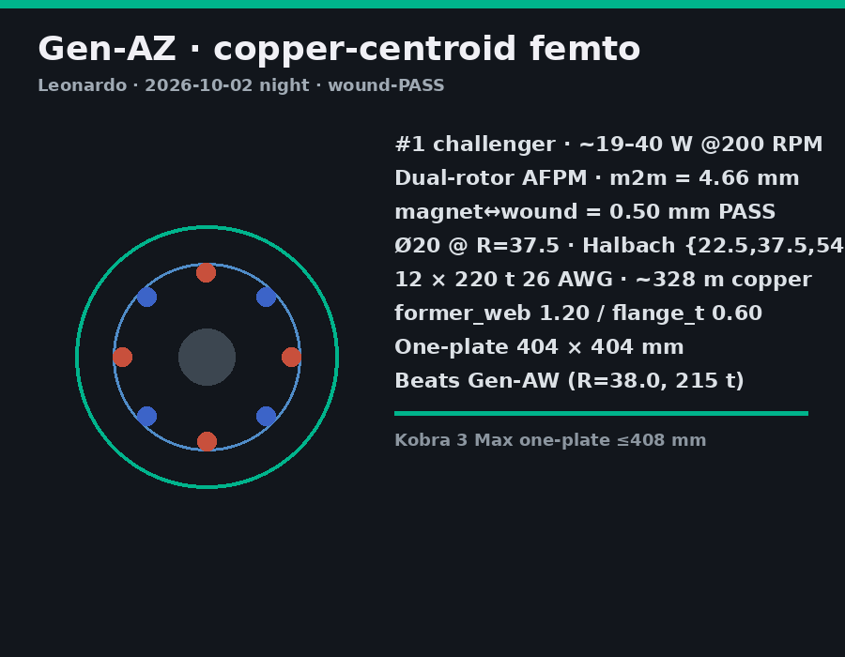
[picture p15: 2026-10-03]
print-packs/gen-az-dual-rotor-coppercentroid-femto/one-plate/preview.png

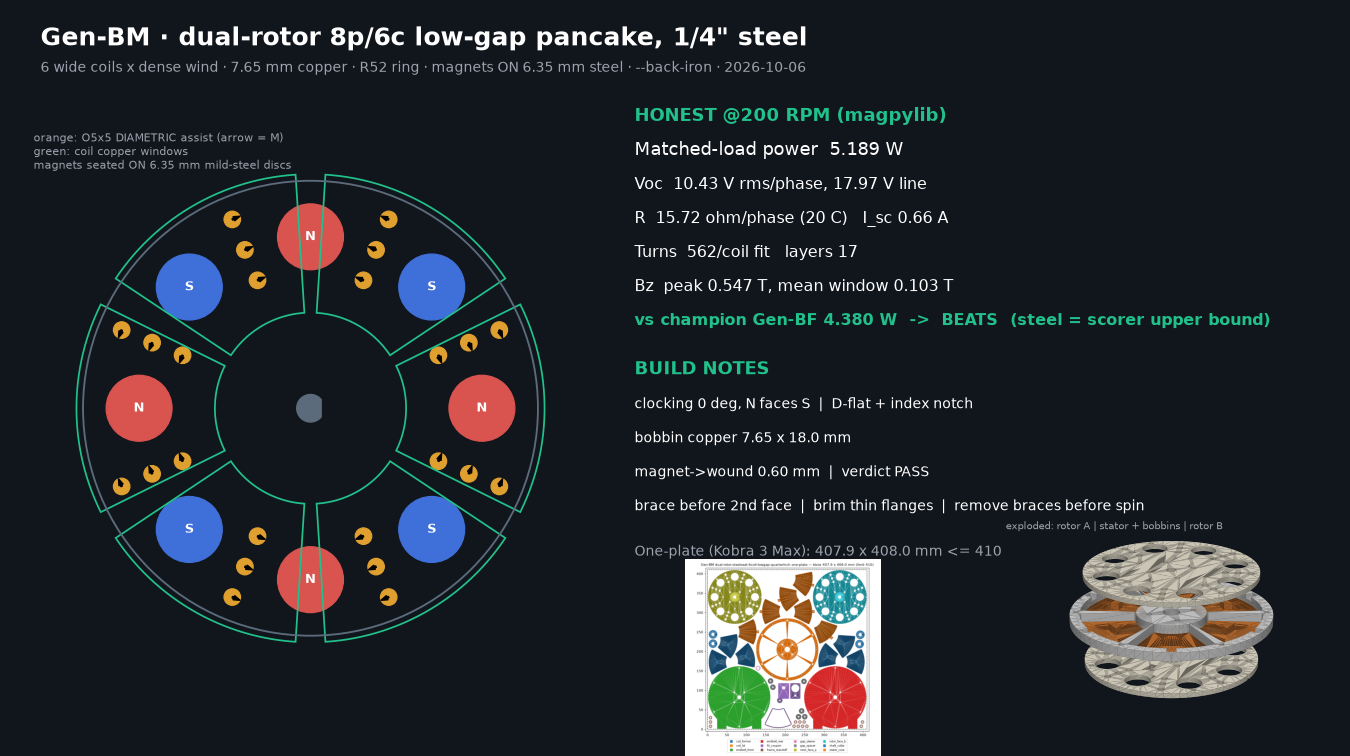
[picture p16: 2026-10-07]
print-packs/gen-bm-dual-rotor-steelseat-6coil-lowgap-quarterinch/preview.png

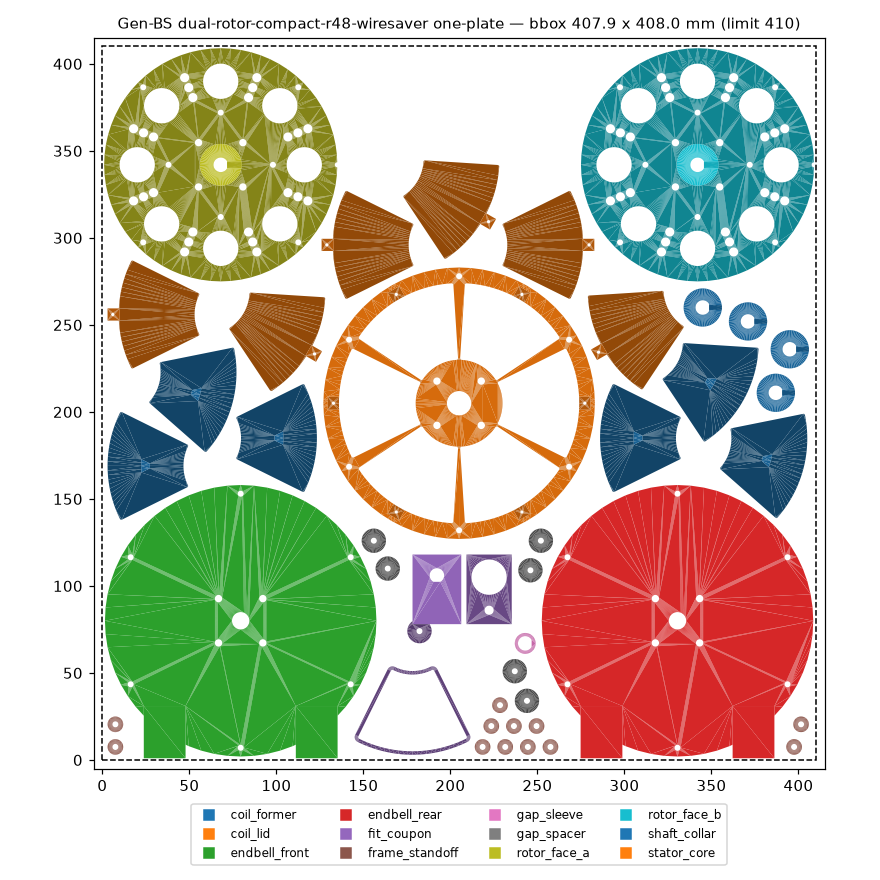
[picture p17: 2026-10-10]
champions/runners-2026-10-09/gen-bs-dual-rotor-compact-r48-wiresaver/print-packs/one-plate/preview.png

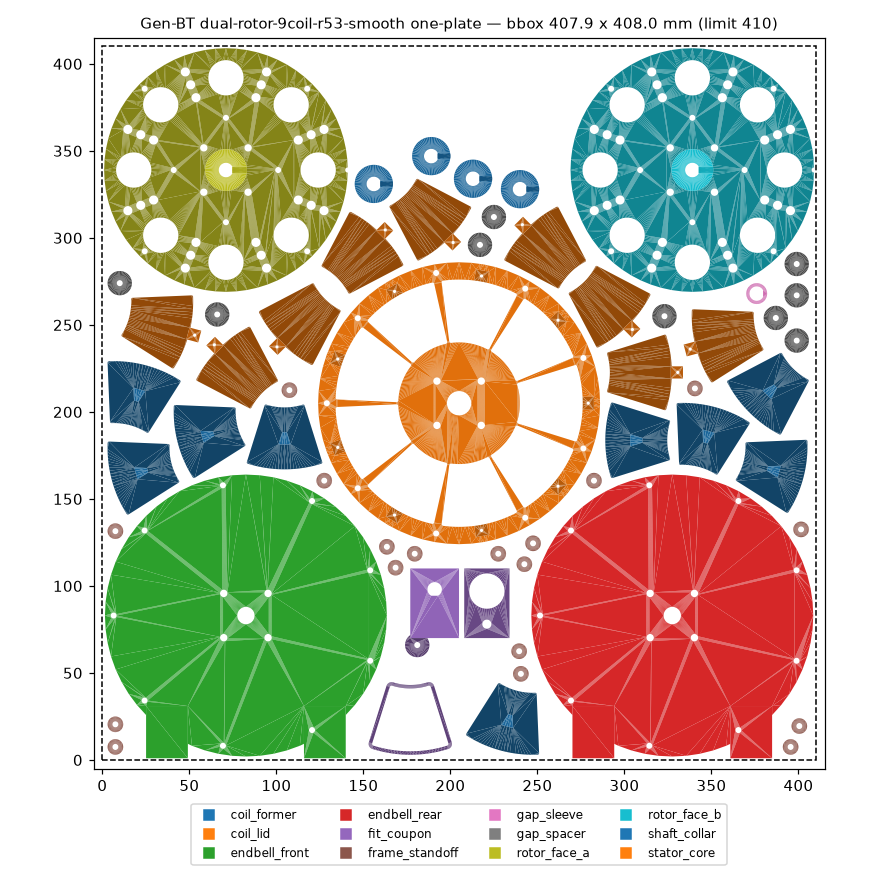
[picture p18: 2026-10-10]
champions/runners-2026-10-09/gen-bt-dual-rotor-9coil-r53-smooth/print-packs/one-plate/preview.png

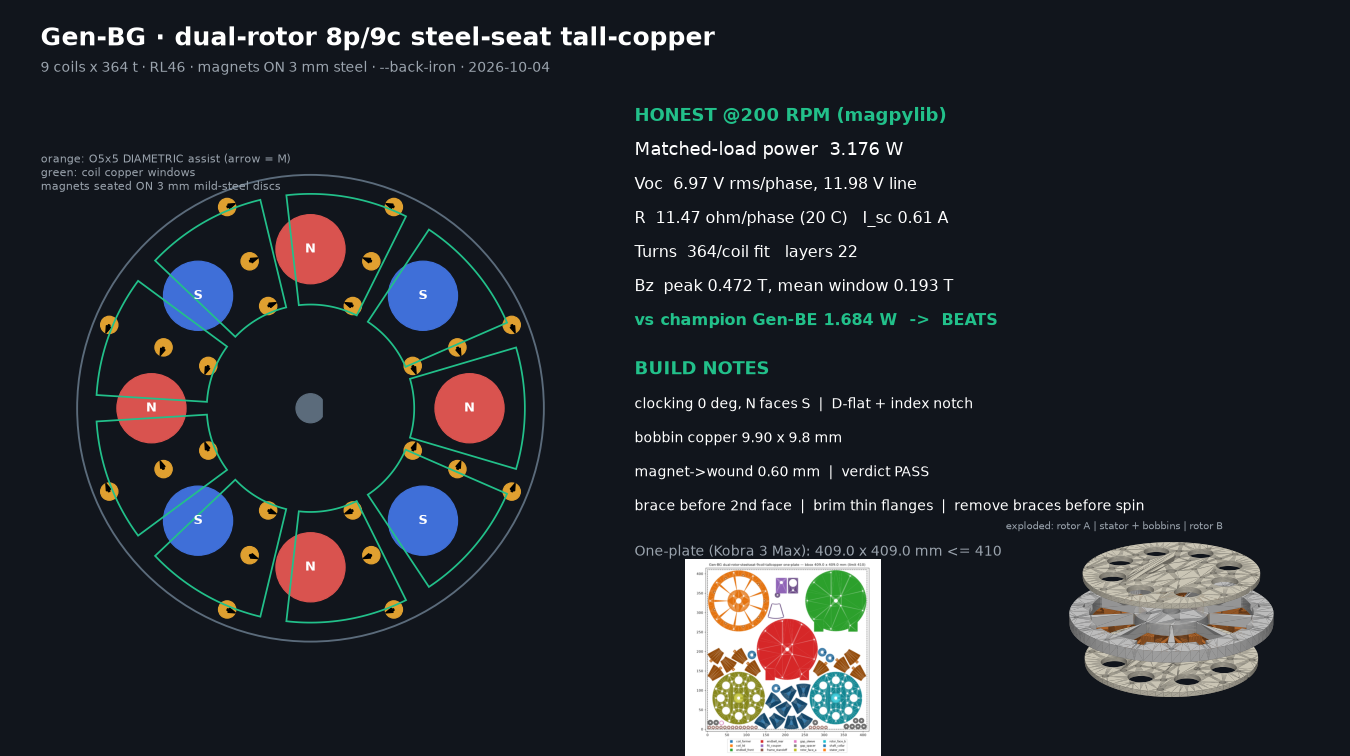
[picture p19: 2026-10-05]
print-packs/gen-bg-dual-rotor-steelseat-9coil-tallcopper/preview.png

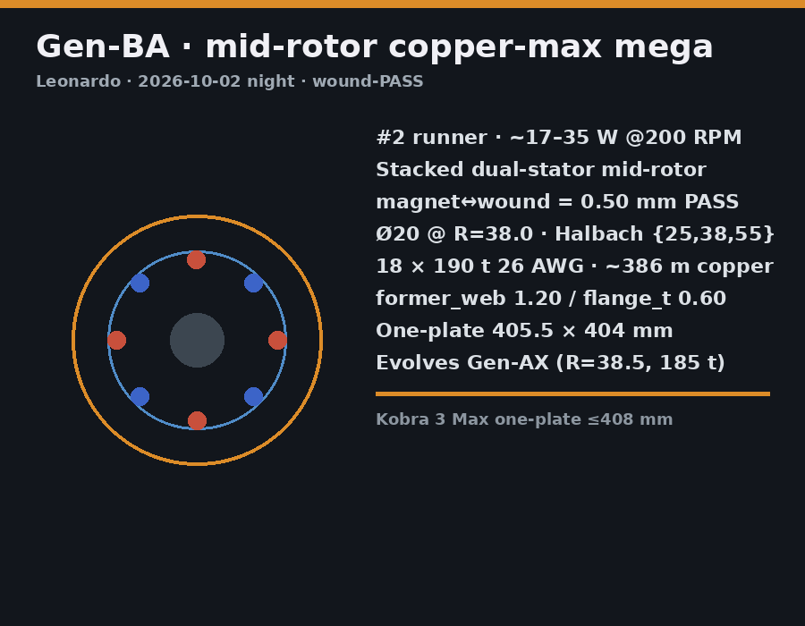
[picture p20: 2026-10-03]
print-packs/gen-ba-stacked-midrotor-coppermax-mega/one-plate/preview.png

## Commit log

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2026-09-18 Add one-plate print packs with previews for Gen-A–F
    Circle-aware Kobra 3 Max (410×410 usable) layouts for every MAX kit:
    one_plate_layout.stl, labeled preview.png, PLATE.md, and parts/_xN STLs.
    Document print-packs in README and CHAMPION.
    [coil_former_x12.stl, coil_former_x6.stl, coil_former_x8.stl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]
2026-09-19 Promote Gen-G Halbach barrel as MAX champion (2026-09-19)
    Nightly triple: Gen-G (~4–9 W) beats Gen-E; add Gen-H AFPM contender and Gen-I claw one-plate packs.
    [claw_return_ring.stl, claw_return_ring_x1.stl, coil_former.scad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]
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2026-09-20 Withdraw Gen-A–L: wound-coil envelope gate (no champion)
    All kits sized gaps/slots to bare formers. Require wind_build/wound_h/coil_envelope
    and ≥0.5–1.0 mm magnet↔wound clearance before any future champion.
    [claw_return_ring.stl, claw_return_ring_x1.stl, coil_former.scad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]
2026-09-20 Promote Gen-M wound-aware dual-stator sandwich as MAX champion
    First wound-compliant kit: explicit wind_build_axial/coil_envelope_h,
    magnet↔wound run_clear 0.85 mm, one-plate pack. Gen-N/O runners PASS.
    [coil_former.scad, coil_former.stl, endbell_front.scad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]
2026-09-21 Nightly 2026-09-20-night: promote Gen-P dual-rotor thin-gap as MAX champion
    Wound-PASS Gen-P (~7–15 W @200, m2m=7.26, magnet↔wound=0.80) dethrones Gen-M.
    Runners Gen-R vernier and Gen-Q concentric barrel also wound-PASS with one-plate packs.
    [coil_former.scad, coil_former.stl, coil_former_x12.stl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]
2026-09-22 2026-09-21 night: Gen-S dual-rotor ultra-thin dethrones Gen-P
    Gen-S (~8–17 W @200 RPM, m2m=6.66, magnet↔wound=0.80) becomes new MAX champion.
    Runners: Gen-T triple-gap (~6.5–14 W), Gen-U vernier flux-claw (~5.5–12 W). All wound-PASS.
    [claw_flux_pad.scad, claw_flux_pad.stl, coil_former.scad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]
2026-09-23 2026-09-22 night: Gen-V dual-rotor nano-gap dethrones Gen-S
    Gen-V (~9–19 W @200 RPM, m2m=6.16, magnet↔wound=0.70) becomes new MAX champion.
    Runners: Gen-W triple-rotor dual-stator (~7–15 W), Gen-X vernier flux-claw dual (~6–13 W). All wound-PASS.
    [coil_former.scad, coil_former.stl, endbell_front.scad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]
2026-09-24 2026-09-23 night: Gen-Y dual-rotor micro-gap dethrones Gen-V
    Gen-Y (#1): dual-rotor micro-gap AFPM ~10–21 W @200 RPM, m2m=5.76,
    magnet↔wound=0.65, 12×150 t 26 AWG (~216 m). Beats Gen-V (~9–19 W, m2m=6.16).
    Gen-Z (#2): dual-stator mid-rotor Halbach ~8–17 W @200, m2m=5.86, 18×115 t.
    Gen-AA (#3): vernier flux-claw nano ~7–15 W @200, m2m=6.16, 12×145 t.
    All three WOUND-PASS. One-plate packs + fit coupons included.
    [coil_former.scad, coil_former.stl, endbell_front.scad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]
2026-09-25 2026-09-24 night: Gen-AB dual-rotor ultra-micro-gap dethrones Gen-Y
    Gen-AB (~11–23 W @200 RPM, m2m=5.22, magnet↔wound=0.58 PASS, 12×160 t 26 AWG)
    beats Gen-Y (~10–21 W, m2m=5.76) via thinner wound envelope + larger copper window
    (ID20–OD62) + +10 turns. Runners: Gen-AC stacked dual-gap Halbach (~9–19 W),
    Gen-AD vernier flux-claw nano (~8–17 W). All wound-PASS.
    [coil_former.scad, coil_former.stl, endbell_front.scad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]
2026-09-26 2026-09-25 night: Gen-AE dual-rotor hyper-micro-gap dethrones Gen-AB
    Wound-PASS MAX tip: m2m=5.00, magnet↔wound=0.52, 12×170 t 26 AWG, ~12–26 W @200 RPM.
    Runners: Gen-AF stacked mid-rotor copper-max (~10–21 W), Gen-AG vernier flux-claw hyper (~9–19 W).
    [coil_former.scad, coil_former.stl, endbell_front.scad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]
2026-09-27 2026-09-26 night: Gen-AH dual-rotor copper-centroid hypermicro dethrones Gen-AE
    Gen-AH (~13–28 W @200, m2m=4.96, magnet↔wound=0.50, Ø20 @ R=41, 180 t)
    beats Gen-AE (~12–26 W, m2m=5.00, R=54, 170 t). Runners Gen-AI (~11–23 W)
    and Gen-AJ (~10–22 W). All wound-PASS. One-plates ≤408 (AH/AJ 404×404,
    AI 405.5×405). Dual-rotor clap warnings documented.
    [coil_former.scad, coil_former.stl, endbell_front.scad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]
2026-09-28 2026-09-27 night: Gen-AK dual-rotor copper-centroid ultra dethrones Gen-AH
    Gen-AK (~14–30 W @200 RPM, m2m=4.86, magnet↔wound=0.50, Ø20 @ R=40,
    12×190 t 26 AWG, copper ~301 m, one-plate 404×404) beats Gen-AH (~13–28 W,
    m2m 4.96, R=41, 180 t). Runners: Gen-AL stacked mid-rotor copper-max plus
    (~12–25 W) and Gen-AM vernier flux-claw hyper (~11–24 W). All wound-PASS.
    [coil_former.scad, coil_former.stl, endbell_front.scad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]
2026-09-29 2026-09-28 night: Gen-AN dual-rotor copper-centroid hyper dethrones Gen-AK
    Gen-AN (~15-32 W @200 RPM, m2m=4.76, magnet↔wound=0.50, Ø20 @ R=39.5,
    12×200 t 26 AWG, former_web 1.30, copper ~312 m) beats Gen-AK (~14-30 W,
    m2m 4.86, R=40, 190 t). Wound-PASS. One-plate 404×404.
    Runners: Gen-AO stacked mid-rotor copper-max ultra (~13-27 W);
    Gen-AP vernier flux-claw mega (~12-26 W). All wound-PASS, spool-legal.
    [coil_former.scad, coil_former.stl, endbell_front.scad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]
2026-09-30 2026-09-29 night: Gen-AQ dual-rotor copper-centroid ultra dethrones Gen-AN
    Gen-AQ (~16-34 W @200 RPM, m2m=4.71, magnet↔wound=0.50 PASS, Ø20 @ R=39.0,
    12×205 t 26 AWG, former_web=1.25, copper ~320 m) beats Gen-AN (~15-32 W,
    m2m=4.76, R=39.5, 200 t). One-plate 404×404. Runners: Gen-AR stacked mid-rotor
    copper-max hyper (~14-29 W), Gen-AS vernier flux-claw ultra (~13-28 W). All wound-PASS.
    [coil_former.scad, coil_former.stl, endbell_front.scad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]
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2026-10-04 2026-10-03 night: Gen-BE dual-rotor backiron 9-coil mega dethrones Gen-AZ
    Honest physics_scorer watts (magpylib, PLA=air, --back-iron): Gen-BE 1.684 W
    @200 RPM beats corrected Gen-BA baseline 0.615 W and supersedes inflated
    Gen-AZ ~19-40 W claims. Runners: Gen-BD 1.174 W (12c dual+steel), Gen-BC
    0.802 W (mid tall-bobbin air-core). Clocking 0, bobbin turns-fit, diametric
    O5 Halbach, buyable steel discs documented.
    [coil_former.scad, coil_former.stl, coil_lid.scad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]
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2026-10-08 2026-10-07 night: Gen-BO dual-rotor flush-seat 6-coil wide-lip dethrones Gen-BL
    Honest physics_scorer watts (magpylib, PLA=air, --back-iron): Gen-BO 5.497 W
    @200 RPM (Voc 11.00 V rms/ph, R 16.51 ohm, 595 t at fill 0.65, 8p/6c, R50 ring,
    2x 4.76 mm steel, 370 m wire; air-core 2.713 W) beats Gen-BL 5.299 W. Flush 5.00 mm
    through-pocket magnet seat (magnet->wound 0.50 mm), 0.8 mm bobbin lip and tighter
    diametric O5 map R43/50/57. Runners: Gen-BP 5.460 W (BL rotor retrofit), Gen-BQ 4.420 W (8p/9c).
    [coil_former.scad, coil_former.stl, coil_lid.scad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]
2026-10-10 2026-10-09 night: Gen-BR Gen-BO rotor retrofit (tight Ø5 map) edges out Gen-BO, 5.507 W
    [coil_former.scad, coil_former.stl, coil_lid.scad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]
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2026-10-21 2026-10-20 night: Gen-CS dual-rotor 8p/12c T-pole on 24 AWG (tall-copper stator, Austin's real wire) dethrones Gen-CP, 19.306 W
    Gen-CS 19.306 W matched @200 RPM --back-iron (air-core 9.139 W, Voc 16.72 V rms/ph, 10.86 ohm, 306 t of 24 AWG, Bz pk 0.568 T, 387 m).
    Same rotors as Gen-CP (O20 N52 @R88 + N42 tangential keyhole, 48 diametric O5, 2x O202 x 4.76 mm steel); bobbins r58-105.5 x 6.8 mm x 16.5 mm; one-plate 399.9x400.8 mm.
    Runners: Gen-CT 19.289 W inverted pole (same stator, rotor swap); Gen-CU 18.375 W 24 AWG wire-saver 337 m. All PASS / geom PASS. Scorer unchanged (sanity PASS, Gen-CP regression 15.820 W).
2026-10-23 2026-10-22 night: Gen-CZ dual-rotor 8p/12c INVERTED triple pole (O20 + N42 block + N52 60x10x3 bar per pole) dethrones Gen-CS, 24.262 W
    Gen-CZ 24.262 W matched @200 RPM --back-iron (air-core 10.945 W, Voc 18.55 V rms/ph, 10.64 ohm, 250 t of 24 AWG, Bz pk 0.580 T, 379 m).
    O20 N52 @R77 + N42 20x10x5 @R92.6 (keyhole) + N52 60x10x3 bar @R103.2 (blind pocket) + 48 diametric O5; bobbins r58-111.5 x 6.1 x 15.0 mm; 2x O229 x 4.76 mm steel; TWO plates 354.3x385.6 + 392.6x401.0 mm.
    Runners: Gen-CX 23.718 W (triple pole, block inside, R87); Gen-CY 21.751 W (Gen-CS upgrade, reuses wound bobbins, one plate). All PASS / geom PASS. Scorer unchanged (sanity PASS, Gen-CS regression 19.306 W).
2026-10-24 2026-10-23 night: Gen-DA dual-rotor 8p/12c inverted triple pole on a thin-gap long-copper 24 AWG stator dethrones Gen-CZ, 25.809 W
    Gen-DA 25.809 W matched @200 RPM --back-iron (air-core 11.626 W, Voc 19.38 V rms/ph, 10.92 ohm, 252 t of 24 AWG, Bz pk 0.601 T, 389 m).
    O20 N52 @R81 + N42 20x10x5 @R96.6 (keyhole) + N52 60x10x3 bar @R107.2 (blind pocket) + 48 diametric O5; bobbins r61-117 x 5.5 x 16.8 mm (gap 8.10 mm); 2x O236 x 4.76 mm steel; TWO plates 382.4x383.0 + 391.3x387.0 mm.
    Runners: Gen-DB 24.839 W (Gen-CZ rotors re-used, new stator, one plate 352.7x385.9); Gen-DC 24.619 W (block-inside order, R90). All PASS / geom PASS. Scorer unchanged (sanity PASS, Gen-CZ regression 24.262 W).
2026-10-25 2026-10-24 night: Gen-DD dual-rotor 8p/12c inverted triple pole R86 on a wide outer 24 AWG stator dethrones Gen-DA, 26.632 W
2026-10-26 2026-10-25 night: Gen-DG dual-rotor 8p/12c inverted triple pole R95 on an 8-layer thin-gap 24 AWG stator dethrones Gen-DD, 27.834 W
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
